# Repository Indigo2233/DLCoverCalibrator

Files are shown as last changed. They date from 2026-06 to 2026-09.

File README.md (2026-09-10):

# DarkLight Cover/Calibrator (DLC)

**DIY 电动天文望远镜盖 + 平场板** — 支持 ASCOM & INDI 全自动控制。

> 基于 [Nathan Woelfle 的原版设计](https://github.com/iwannabswiss/DarkLight_CoverCalibrator) 修改，遵循 CC BY-NC 4.0 协议。

---

## 三种构建方式

- **纯平场板** — 壁挂式校准面板（无需舵机）
- **纯电动盖** — 翻转盖，拍暗场和天光平场
- **Flip-Flat 组合** — 舵机 + 发光面板一体

---

## 🆕 改进亮点

| 改进 | 说明 |
|---|---|
| 🔧 **角度实时配置** | 不再需要刷固件！通过 ASCOM/INDI 软件直接调整开合角度 |
| 📡 **开源 ASCOM 驱动** | 从零编写，源码完全开放，Setup 界面配置角度 |
| 💾 **EEPROM 持久化** | 角度设置掉电保存，无需每次连接重新配置 |

---

## 📁 项目结构

```
├── dlc_firmware/          Arduino 固件
│   ├── dlc_firmware.ino   主程序
│   └── DLC_Library/       依赖库 (舵机/传感器/EEPROM)
├── esp8266_lenscap/       ESP8266 无线电动镜头盖固件
│   └── README.md           NodeMCU / Wemos 接线、刷写与 WiFi 使用说明
├── ascom/                 ASCOM 驱动 (Windows)
│   ├── DarkLightDriver/   🆕 自定义开源驱动 (C#)
│   └── *.msi/*.exe        原版闭源驱动
├── indi/                  INDI 驱动 (Linux/macOS)
│   └── indi-dlc-src/      C++ 源码
├── schematics/            硬件原理图 & PCB
└── docs/                  📚 文档
    ├── getting-started.md
    ├── firmware.md
    ├── protocol.md
    ├── ascom-driver.md
    ├── indi-driver.md
    └── changelog.md
```

---

## 🚀 快速开始

### ESP8266 无线镜头盖

使用 NodeMCU 或 Wemos D1 Mini 驱动舵机时，请参阅 [ESP8266 镜头盖固件说明](esp8266_lenscap/README.md)。

### 1. 刷固件
用 Arduino IDE 打开 `dlc_firmware/dlc_firmware.ino`，按需修改配置后上传。详见 [固件指南](docs/firmware.md)。

### 2. 安装驱动

**Windows（自定义开源驱动）:**
```batch
cd ascom\DarkLightDriver
dotnet build -c Release
Install.bat
```
详见 [ASCOM 驱动指南](docs/ascom-driver.md)。

**Linux:**
```bash
cd indi/indi-dlc-src
mkdir build && cd build
cmake .. && make -j$(nproc) && sudo make install
```
详见 [INDI 驱动指南](docs/indi-driver.md)。

### 3. 配置角度（🆕）
- **ASCOM**: Properties → Setup 界面直接修改
- **INDI**: Options 面板修改角度数值
- 自动保存到 EEPROM，无需重新刷固件

详细串口协议见 [通信协议文档](docs/protocol.md)。

---

## 📜 许可

© 2020–2025 Nathan Woelfle (10th Tee Astronomy).  
修改部分 © 2025.

[CC BY-NC 4.0](https://creativecommons.org/licenses/by-nc/4.0/) — 个人/学术用途自由使用，商用需授权。

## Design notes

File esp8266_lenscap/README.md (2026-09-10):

# ESP8266 电动镜头盖 — 精简版

## 当前网络功能

- 唯一 AP：`LensCap-<设备ID>`，默认密码 `telescope`
- 控制页面：`http://192.168.4.1/`，支持盖板控制和平场灯 1–255 亮度调节
- 配置页面：`http://192.168.4.1/config`，可配置 STA、开盖位置和关盖位置，参数保存到 EEPROM
- DLC TCP 服务：端口 `4030`，协议与 USB 串口相同，命令使用 `<`、`>` 封装
- AP 在 STA 模式下保持启用，便于连接失败时恢复配置

ASCOM 使用 USB 时选择 `Serial` 和 115200 baud；使用 WiFi 时选择 `TCP`，填写配置页显示的 STA IP 和端口 `4030`。

基于 ESP8266 + 舵机的无线电动天文望远镜盖。
**完全兼容 DLC ASCOM/INDI 驱动。**

## 特性

| 功能 | 说明 |
|---|---|
| 📱 **Web 控制** | 手机/电脑浏览器打开网页即可开关盖子 |
| 🔘 **物理按键** | 短按切换开关状态（可选，不接也行） |
| 🔌 **ASCOM/INDI** | ✅ 完整 DLC 串口协议，直接配合现有驱动使用 |
| 💾 **角度持久化** | EEPROM 保存开合角度，ASCOM Setup 界面修改自动保存 |
| 📡 **WiFi AP** | 自带热点，野外无路由器也能用 |
| ⚡ **平滑移动** | 线性插值缓动，可设移动时间 |

## ASCOM/INDI 兼容性

| 命令组 | 状态 | 说明 |
|---|:----:|---|
| 盖子 O/C/H/P | ✅ 完整支持 | 开关盖、停止、状态查询 |
| 角度 UO/UC/uO/i | ✅ 完整支持 | ASCOM Setup 里直接改角度，自动写入 EEPROM |
| 平场板 L/B/M/T/F | ✅ 兼容应答 | 本设备无平场板，返回 NotPresent/0 |
| 加热器 R/W/Y | ✅ 兼容应答 | 本设备无加热器，返回 NotPresent/0 |
| 系统 V/Z | ✅ 完整支持 | 版本查询、握手 |

> 在 NINA / SGPro / KStars 中直接选择 "DarkLight Cover Calibrator" 驱动即可使用。
> ASCOM 驱动轮询平场板和加热器状态时不会报错。

## 硬件接线

```
Wemos D1 Mini / NodeMCU      外部器件
────────────────────────     ──────────
D2 (GPIO4)  ──────────────   舵机 信号线 (橙/黄)
5V / VIN    ──────────────   舵机 电源 (红)  ← 必须独立供电
GND         ──────────────   舵机 GND  (棕)
GND         ──────────────   电源 GND
D1 (GPIO5)  ───[按键]─── GND
D3 (GPIO0)  ───[LED]──── GND  (可选，状态指示)
```

> ⚠️ **重要**: 舵机电源必须接 **5V pin** 或外部 5V 电源，**不要接 3.3V pin**！
> MG996R 等大扭矩舵机建议独立 5V/2A 供电。

### NodeMCU ESP-12F 接线（CH340 版本）

本固件已在 NodeMCU ESP-12F 开发板上验证。该板上标记为 `VU` 的针脚是 USB 5V 电源，外观上容易与 `VV` 混淆。

| 舵机线 | NodeMCU 针脚 | 说明 |
|---|---|---|
| 白 / 橙 / 黄 | `D2`（GPIO4） | 控制信号 |
| 红 | `VU` | USB 5V；适用于 SG90 等小型舵机 |
| 黑 / 棕 | `G` | 接地 |

`D2` 位于下排、靠右侧第三个 I/O 针脚。`3V` 针脚不用于舵机供电。

对于 MG90、MG996R 等电流较大的舵机，将红线连接到独立的稳定 5V 电源；外部电源 GND 与 NodeMCU 的 `G` 必须共地。建议在舵机电源线附近并联一个 **470–1000 µF、耐压至少 6.3V** 的电解电容，电容正极接 5V、负极接 GND；可另加 0.1 µF 陶瓷电容抑制高频干扰。

## 固件配置

打开 `esp8266_lenscap.ino`，修改顶部 `USER CONFIGURATION` 区域：

```cpp
// WiFi 热点名称和密码
const char* apSSID = "LensCap";
const char* apPassword = "telescope";  // 至少 8 位，空字符串 = 不加密

// 舵机角度 (0-180)
const uint16_t OPEN_ANGLE = 0;      // 开盖角度
const uint16_t CLOSE_ANGLE = 180;   // 关盖角度
const uint16_t MOVE_TIME_MS = 2000; // 开合时间 (毫秒)

// 舵机脉冲范围 (查舵机说明书)
const uint16_t SERVO_MIN_US = 500;
const uint16_t SERVO_MAX_US = 2500;
```

## 刷写步骤

1. **安装 ESP8266 开发板支持**  
   Arduino IDE → 文件 → 首选项 → 附加开发板管理器网址，添加：  
   `http://arduino.esp8266.com/stable/package_esp8266com_index.json`  
   然后：工具 → 开发板 → 开发板管理器 → 搜索 `ESP8266` → 安装

2. **选择开发板**  
   - Wemos D1 Mini：工具 → 开发板 → ESP8266 → **LOLIN(WEMOS) D1 R2 & mini**
   - NodeMCU ESP-12F：工具 → 开发板 → ESP8266 → **NodeMCU 1.0 (ESP-12E Module)**

3. **安装依赖库**  
   工具 → 管理库 → 搜索并安装：
   - `ESP8266WiFi` (自带)
   - `ESP8266WebServer` (自带)
   - `Servo` (自带，但 ESP8266 版在 ESP8266 包中)

4. **上传**  
   连接 USB，选择端口，点击上传。

## 使用

### 方式一：手机 Web 控制 (推荐)

1. 上电后 ESP8266 创建热点 `LensCap-<设备ID>`（密码 `telescope`）
2. 手机连接该 WiFi
3. 浏览器打开 **http://192.168.4.1**
4. 点击按钮开关盖子

设备 ID 取自 ESP8266 芯片 ID 的十六进制后六位。例如，芯片 ID 为 `513670` 时，热点名称为 `LensCap-513670`。

### 方式二：物理按键

按一下按键 → 切换开关状态（关→开，开→关）

### 方式三：串口命令 (ASCOM/INDI)

通过 USB 串口发送命令（115200 baud）：

| 命令 | 功能 |
|---|---|
| `<O>` | 开盖 |
| `<C>` | 关盖 |
| `<H>` | 立即停止 |
| `<P>` | 查询状态 (1=关,2=移动中,3=开,5=错误) |

此协议兼容 DLC 固件子集，可直接配合 ASCOM/INDI 驱动使用。

## 结构设计建议

### 3D 打印件

- [Thingiverse: Telescope Lens Cap Servo Mount](https://www.thingiverse.com/search?q=telescope+lens+cap+servo)
- 设计要点：舵机固定在镜筒侧面，连杆连接盖子

### 简易方案 (无需 3D 打印)

```
舵机 ──[连杆]── 盖子 (3D 打印件 / 亚克力切割 / 硬纸板+黑色植绒)
  │
  ├── 用抱箍/扎带固定在望远镜镜筒上
  └── 舵机转轴与盖子轴心对齐
```

## 可选增强

| 功能 | 实现方式 |
|---|---|
| 接入家庭 WiFi | 取消 `WIFI_STA_MODE` 注释，填写路由器 SSID/密码 |
| MQTT 远程控制 | 添加 `PubSubClient` 库，接入 Home Assistant |
| 平场板集成 | 加 LED 灯板 + MOSFET，用 GPIO 控制亮度 |
| 电池供电 | 2S 锂电池 (7.4V) + LM2596 降压模块 → 5V |
| 低功耗 | 加 `ESP.deepSleep()`，按键唤醒 |

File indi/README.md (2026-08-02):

# INDI Driver: DarkLight Cover Calibrator

This is the INDI driver source code for the **DarkLight Cover Calibrator (DLC)**. It enables control of the DLC hardware via the INDI protocol, providing compatibility with astronomy software on Linux systems.

---

## 🔖 Firmware Version

📄 See full [INDI Version History](https://github.com/10thTeeAstronomy/DarkLight_CoverCalibrator/wiki/INDI-Version-History)

---

## 📦 Features

- Cover control (Open/Close/Halt)  
- Calibrator control (On/Off/Brightness)  
- Dew heater  control  
- Support for ASCOM-style commands over INDI  
- Fully compatible with INDI clients like KStars and Ekos  

---

## 🛠️ Building and Installing

To compile and install the driver from source:

### 1. Clone the repository
```bash
git clone https://github.com/Indigo2233/DLCoverCalibrator.git
cd DLCoverCalibrator/indi/indi-dlc-src
```

### 2. Create a `build` directory
```bash
mkdir build
cd build
```

### 3. Run `cmake`
```bash
cmake -DCMAKE_INSTALL_PREFIX=/usr -DCMAKE_BUILD_TYPE=Release ..
```

### 4. Compile the driver
```bash
make
```

### 5. Install the driver
```bash
sudo make install
```

---

## 📚 Resources

- Main Project: [DarkLight Cover Calibrator GitHub](https://github.com/10thTeeAstronomy/DarkLight_CoverCalibrator)  
- Firmware: [dlc_firmware](https://github.com/10thTeeAstronomy/DarkLight_CoverCalibrator/tree/main/dlc_firmware)  
- Documentation: See the [GitHub Wiki](https://github.com/10thTeeAstronomy/DarkLight_CoverCalibrator/wiki)  

---

## 🤝 Contributing

We welcome contributions! Please see the `CONTRIBUTING.md` file in the root project for intallation and guidelines on submitting pull requests.

---

## 📜 License

© 2020–2025 10th Tee Astronomy. All rights reserved.

This project is licensed under the  
**Creative Commons Attribution-NonCommercial 4.0 International License**.

- You may share and adapt the materials for personal or academic use  
- Commercial use is prohibited without written permission  
- Modified versions must credit the original work  

See `LICENSE.md` for full terms.  

**Happy imaging!**  
— *The 10thTeeAstronomy Team*

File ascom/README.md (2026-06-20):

# ASCOM Driver and Application

This is the ASCOM-compatible driver and application for the **DarkLight Cover Calibrator (DLC)**. It provides full support for Windows-based astronomy applications that use the ASCOM platform.

> 🆕 **Custom Open-Source Driver**: See [DarkLightDriver/](DarkLightDriver/) for a from-scratch, open-source ASCOM driver with **configurable servo open/close angles** — no more firmware flashing to adjust angles!

---

## 🔖 Firmware Version

📄 See full [ASCOM Version History](https://github.com/10thTeeAstronomy/DarkLight_CoverCalibrator/wiki/ASCOM-Version-History)

---

## 📦 Features

- Full support and compliance using the ASCOM **ICoverCalibratorV2** interface  
- Cover control (Open/Close/Halt)  
- Light control with adjustable brightness  
- Dew heater support (manual, automatic, and "on close" modes)  
- Standalone Windows application available 

---

## 🛠️ Installing the Driver

To install the driver:

1. **Clone** or **Download** the latest [Release](https://github.com/10thTeeAstronomy/DarkLight_CoverCalibrator/releases).
2. **Open** the ```ascom``` folder.
2. **Run the installer**, ```DarkLight_Driver_Setup```, and follow the on-screen instructions.
3. Once installed, the driver will appear in the ASCOM Chooser as:
   ```
   DarkLight Cover Calibrator
   ```

> ℹ️ ASCOM Platform 7 or newer is required for DLC version 1.2 and newer. You can download it from [ascom-standards.org](https://ascom-standards.org/).

---

## ⚙️ Configuring the Driver

Refer to the [ASCOM Integration Guide](https://github.com/10thTeeAstronomy/DarkLight_CoverCalibrator/wiki/ASCOM-Integration).

---

## 🪟 Installing the Application

To install the application:

1. **Clone** or **Download** the latest [Release](https://github.com/10thTeeAstronomy/DarkLight_CoverCalibrator/releases).
2. **Open** the ```ascom``` folder.
2. **Run the installer**, ```DarkLight_App_Setup```, and follow the on-screen instructions.
3. Once installed, run the program and select the ```DarkLight Cover Calibrator```.

---

## ⚙️ Configuring the Application

Refer to the [Windows Application Guide](https://github.com/10thTeeAstronomy/DarkLight_CoverCalibrator/wiki/Windows-Application).

---

## 📚 Resources

- Main Project: [DarkLight Cover Calibrator GitHub](https://github.com/10thTeeAstronomy/DarkLight_CoverCalibrator)  
- Firmware: [dlc_firmware](https://github.com/10thTeeAstronomy/DarkLight_CoverCalibrator/tree/main/dlc_firmware)  
- Documentation: See the [GitHub Wiki](https://github.com/10thTeeAstronomy/DarkLight_CoverCalibrator/wiki)  
- ASCOM CoverCalibrator Info: [ASCOM Device Interface](https://ascom-standards.org/help/developer/html/T_ASCOM_DeviceInterface_ICoverCalibratorV2.htm)

---

## 🤝 Contributing

We welcome contributions! Please see the `CONTRIBUTING.md` file in the root project for guidelines on submitting pull requests.

---

## 📜 License

© 2020–2025 10th Tee Astronomy. All rights reserved.

This project is licensed under the  
**Creative Commons Attribution-NonCommercial 4.0 International License**.

- You may share and adapt the materials for personal or academic use  
- Commercial use is prohibited without written permission  
- Modified versions must credit the original work  

See `LICENSE.md` for full terms.  

**Happy imaging!**  
— *The 10thTeeAstronomy Team*

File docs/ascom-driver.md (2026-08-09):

# 自定义 ASCOM 驱动

源码位于 `ascom/DarkLightDriver/`，是从头编写的开源 ASCOM CoverCalibrator V2 驱动。

## 与原版驱动的对比

| 功能 | 原版驱动 (闭源) | 本驱动 (开源) |
|---|:---:|:---:|
| Cover 开/关/停 | ✓ | ✓ |
| 平场板亮度控制 | ✓ | ✓ |
| 除露加热控制 | ✓ | ✓ |
| 宽带/窄带亮度预设 | ✓ | ✓ |
| **主舵机开合角度配置** | ✗ | **✓** |
| **源码可修改** | ✗ | **✓** |

## 项目结构

```
ascom/DarkLightDriver/
├── DarkLightDriver.csproj    # .NET Framework 4.8 项目
├── Driver.cs                 # ICoverCalibratorV2 主驱动
├── DeviceSerial.cs           # 串口通信封装
├── SetupDialogForm.cs        # 配置对话框
├── Properties/AssemblyInfo.cs
├── Install.bat               # 安装脚本
├── Uninstall.bat             # 卸载脚本
└── README.md
```

## 编译要求

- Windows 10/11
- [ASCOM Platform 7+](https://ascom-standards.org/)
- .NET Framework 4.8 SDK
- Visual Studio 2022 或 `dotnet` CLI

## 编译

```batch
cd ascom\DarkLightDriver
dotnet build -c Release
```

## 安装

1. **以管理员身份**打开命令行
2. 运行安装脚本：
   ```batch
   Install.bat
   ```
3. 驱动会注册到 COM，出现在 ASCOM Chooser 中

## 卸载

```batch
Uninstall.bat
```

## Setup 界面

在 ASCOM Chooser 中选中驱动，点击 **Properties** 打开配置：

### Serial Connection
- **COM Port** — 下拉选择 + ↻ 刷新按钮
- **Baud Rate** — 9600 / 19200 / 38400 / 57600 / **115200** / 230400

### Servo Angles
- **Open Angle** — 开盖时舵机目标角度 (0–270°)
- **Close Angle** — 关盖时舵机目标角度 (0–270°)

### Polling
- **Poll Interval** — 状态轮询间隔 (500–10000 ms)

## 工作流程

1. 用户在 **Setup 界面**配置角度 → 保存到 Windows 注册表
2. 驱动 **连接设备**时 → 自动将角度推送到固件 EEPROM
3. 每次 **Open/Close** 命令前 → 重新同步确保角度一致
4. 驱动持续**轮询**设备状态，更新 `CoverState` / `CalibratorState`

## 故障排查

| 问题 | 解决方案 |
|---|---|
| 驱动不在 Chooser 中 | 以管理员运行 `Install.bat` |
| 连接失败 | 检查 COM 端口和 115200 波特率 |
| 握手失败 | 固件需编译 `ENABLE_SERIAL_CONTROL` |
| 运行中连续无响应 | 驱动会自动停止轮询、执行 DTR 复位并重建串口 |
| 自动恢复失败 | 在 ASCOM Actions 中执行 `ResetDevice`；仍失败时重新插拔 USB，或在设备管理器中禁用后重新启用 CH340 |
| 角度设置无效 | 更新固件支持 `UO`/`UC` 等命令 |

## 技术细节

- **接口**: `ICoverCalibratorV2` (ASCOM Platform 7)
- **通信**: Serial port, `<command>` 帧协议
- **持久化**: ASCOM Profile (Windows Registry)
- **轮询**: `System.Timers.Timer` 定时刷新状态
- **线程安全**: 串口操作和连接切换使用互斥保护，轮询回调禁止重入
- **恢复策略**: 握手失败时执行一次 DTR 复位和串口重建；运行期连续两次轮询失败后自动恢复

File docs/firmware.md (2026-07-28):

# 固件配置指南

固件文件：`dlc_firmware/dlc_firmware.ino`

## 当前 DLC 板烧录信息

当前通过 CH340 串口连接的 DLC 板实际使用 **ATmega328PB**。应通过
[MiniCore](https://github.com/MCUdude/MiniCore) 编译和上传；Arduino Nano 的
`arduino:avr:nano` 配置无法与该板的 bootloader 正常握手。

- 开发板索引：`https://mcudude.github.io/MiniCore/package_MCUdude_MiniCore_index.json`
- MiniCore 版本：`3.1.2`
- 开发板 FQBN：`MiniCore:avr:328:variant=modelPB`
- 默认配置：外部 16 MHz、UART0 bootloader、保留 EEPROM
- 当前 Windows 串口：`COM3`（端口号可能随 USB 接口变化）
- 固件串口速率：`115200`

安装 MiniCore：

```powershell
arduino-cli core update-index --additional-urls "https://mcudude.github.io/MiniCore/package_MCUdude_MiniCore_index.json"
arduino-cli core install MiniCore:avr --additional-urls "https://mcudude.github.io/MiniCore/package_MCUdude_MiniCore_index.json"
```

编译并烧录：

```powershell
arduino-cli compile --fqbn MiniCore:avr:328:variant=modelPB --libraries dlc_firmware/DLC_Library dlc_firmware
arduino-cli upload -p COM3 --fqbn MiniCore:avr:328:variant=modelPB dlc_firmware
```

烧录完成后，可通过串口发送 `<V>` 验证固件响应。2026-07-27 的烧录结果为
`<v1.2.0>`。

## 配置选项一览

固件顶部 **User-Adjustable Options (UA)** 区域可以调整所有参数：

### 功能开关

```cpp
#define COVER_INSTALLED        // 启用盖子（舵机）
#define LIGHT_INSTALLED        // 启用平场板
#define HEATER_INSTALLED       // 启用除露加热
#define ENABLE_SERIAL_CONTROL  // 启用串口控制（ASCOM/INDI）
#define ENABLE_MANUAL_CONTROL  // 启用手动物理按钮
#define ENABLE_SAVING_TO_MEMORY // 启用 EEPROM 掉电保存
```

> 不需要的功能直接注释掉即可，固件会自动调整状态上报。

### 串口速率

```cpp
const uint32_t serialSpeed = 115200;
```

可选值：`9600`、`19200`、`38400`、`57600`、`115200`（默认）、`230400`

### 舵机参数

```cpp
// 脉冲宽度 — 查阅舵机说明书设置
const uint16_t primaryServoMinPulseWidth = 500;   // μs
const uint16_t primaryServoMaxPulseWidth = 2500;  // μs

// 开合角度 — 可通过 ASCOM/INDI 实时修改，自动保存到 EEPROM
uint16_t primaryServoOpenCoverAngle = 0;    // 开盖角度 (0–270)
uint16_t primaryServoCloseCoverAngle = 180; // 关盖角度 (0–270)
```

### 盖子移动

```cpp
const uint32_t timeToMoveCover = 5000;  // 开合全程时间 (ms)
```

### 缓动曲线

7 种可选，只取消注释一个：
| 宏 | 效果 |
|----|---|
| `USE_LINEAR` | 匀速（默认） |
| `USE_QUAD` | 二次缓动 |
| `USE_CUBIC` | 三次缓动 |
| `USE_QUART` | 四次缓动 |
| `USE_QUINT` | 五次缓动 |
| `USE_SINE` | 正弦缓动 |
| `USE_EXPO` | 指数缓动 |
| `USE_CIRCULAR` | 圆形缓动 |

### 平场板

```cpp
uint8_t maxBrightness = 255;  // 亮度等级数（越大越细腻）
bool autoON = false;          // 仅手动模式：关盖时自动开灯
```

### 除露加热

```cpp
const uint32_t heaterShutoff = 3600000;  // 手动加热最长持续时间 (ms)
const float deltaPoint = 5.0;             // 目标温度高于环境温度 (°C)
```

### 副舵机

如果需要双舵机驱动：
```cpp
#define SECONDARY_SERVO_INSTALLED  // 取消注释
```

## 角度实时调整（新功能）

不再需要修改固件重新烧录！通过 ASCOM Setup 界面或 INDI Options 面板直接修改角度：

- **主舵机开盖角度** (`UO<N>`) — 0–270°
- **主舵机关盖角度** (`UC<N>`) — 0–270°
- **副舵机开盖角度** (`VO<N>`) — 0–270°（需启用副舵机）
- **副舵机关盖角度** (`VC<N>`) — 0–270°（需启用副舵机）

修改后自动保存到 EEPROM，断电不丢失。

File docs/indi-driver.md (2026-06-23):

# INDI 驱动

源码位于 `indi/indi-dlc-src/`，支持 Linux/macOS 上的 INDI 协议。

## 编译与安装

```bash
cd indi/indi-dlc-src
mkdir build && cd build
cmake -DCMAKE_INSTALL_PREFIX=/usr -DCMAKE_BUILD_TYPE=Release ..
make -j$(nproc)
sudo make install
```

## 依赖

- libindi (INDI 开发库)
- CMake 3.0+

Ubuntu/Debian 安装依赖：
```bash
sudo apt install libindi-dev cmake build-essential
```

## 属性面板

连接设备后在 INDI 控制面板可看到：

### Main Control 选项卡

| 属性 | 类型 | 说明 |
|---|---|---|
| Cover State | 只读文本 | 盖子状态 (Open/Closed/Moving/Error) |
| Open / Close / Halt | 开关按钮 | 控制盖子动作 |
| Light State | 只读文本 | 平场板状态 |
| On / Off | 开关按钮 | 开关平场板 |
| Max Brightness | 只读数字 | 最大亮度值 |
| Current Brightness | 只读数字 | 当前亮度 |
| Goto Brightness | 输入数字 | 跳转到指定亮度 |
| - / + | 按钮 | 步进调整亮度 |
| Broadband / Narrowband | 按钮 | 跳转到预设值 |
| Save as Broadband / Narrowband | 按钮 | 保存当前值为预设 |
| Heater State | 只读文本 | 加热器状态 |
| On / Off / Auto / Heat on Close | 开关按钮 | 加热控制 |

### Options 选项卡

| 属性 | 说明 |
|---|---|
| Stabilize Time | 平场板稳定时间 (ms) |
| Auto ON at CLOSE | 关盖时自动开灯 |
| Disable Light while OPEN | 开盖时禁用灯光 |
| Auto Heat (always ON) | 常开自动除露 |
| Heat ON at CLOSE | 关盖时开启加热 |
| 🆕 **Open Angle (0–270)** | **主舵机开盖角度** |
| 🆕 **Close Angle (0–270)** | **主舵机关盖角度** |
| 🆕 **2nd Open Angle (0–270)** | **副舵机开盖角度** |
| 🆕 **2nd Close Angle (0–270)** | **副舵机关盖角度** |

## KStars / Ekos 集成

1. 启动 INDI 服务
2. 在 Ekos 中配置设备
3. 选择 "DarkLight Cover Calibrator"
4. 平场拍摄时自动调用 `CalibratorOn()`
5. 暗场拍摄时自动调用 `CloseCover()` + `CalibratorOff()`

## 架构

```
Ekos/KStars
    │ INDI Protocol (TCP)
    ▼
indi-dlc driver (C++)
    │ Serial Protocol (<cmd>)
    ▼
Arduino DLC Firmware
    │ PWM / GPIO
    ▼
Servo / LED / Heater
```

驱动类 `DarkLight_CoverCalibrator` 继承 `INDI::DefaultDevice`，通过 `Connection::Serial` 管理串口连接。

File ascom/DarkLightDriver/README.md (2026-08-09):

# DarkLight Cover Calibrator — Custom ASCOM Driver

## 1.2.0 连接方式

- `Serial`：Arduino Nano 或 ESP8266 USB 串口，默认 115200 baud
- `TCP`：ESP8266 的 STA/AP 地址，默认端口 `4030`

两种传输使用相同的 DLC `<命令>` 协议。TCP 模式下建议在路由器为设备保留固定 DHCP 地址。

这是一个从头编写的 ASCOM CoverCalibrator V2 驱动，支持直接配置舵机开合角度。

## 与原版驱动的区别

| 功能 | 原版驱动 | 本驱动 |
|---|---|---|
| Cover 开/关/停 | ✓ | ✓ |
| 平场板亮度控制 | ✓ | ✓ |
| 除露加热控制 | ✓ | ✓ |
| **主舵机开合角度配置** | ✗ (需刷固件) | **✓ (Setup 界面)** |
| 源码可修改 | ✗ (闭源) | **✓ (开源)** |

## 前提条件

- Windows 10/11
- [ASCOM Platform 7](https://ascom-standards.org/) 或更新版本
- .NET Framework 4.8
- DLC 固件已刷入并支持角度命令（`UO`、`UC`、`uO`、`i`）

## 编译

```bash
# 在 Windows 上使用 Visual Studio 或命令行：
cd ascom/DarkLightDriver
dotnet build -c Release
```

或者用 Visual Studio 打开 `DarkLightDriver.csproj`，直接 Build。

## 安装

1. 确保已安装 ASCOM Platform 7+
2. 编译项目得到 `DarkLight.CoverCalibrator.dll`
3. **以管理员身份**运行 `Install.bat`

## 配置（Setup 界面）

在 ASCOM Chooser 中选中 "DarkLight Cover Calibrator"，点击 **Properties**。

界面采用 **Gemini FlatPanel 风格**，支持连接设备后的**实时角度微调**：

### Serial Connection（顶部工具栏）
- **COM Port** — 下拉选择 + ↻ 刷新
- **Baud Rate** — 9600~230400
- 连接状态指示灯 + 固件版本显示

### 舵机角度

每个面板包含两组控制：

**关闭方向** (橙色)
- 当前角度值（大字体）+ **±1° / ±10° / ±45°** 实时微调
- 「设为关闭位置」一键保存当前位置

**打开方向** (绿色)
- 当前角度值（大字体）+ **±1° / ±10° / ±45°** 实时微调
- 「设为打开位置」一键保存当前位置

### 底部按钮
- **重设** — 恢复默认角度（开=0° 关=180°）
- **Done** — 保存并关闭

### 实时微调工作流
1. 连接设备后打开 Setup 界面
2. 点击 ±1°/±10°/±45° 按钮实时移动舵机到位
3. 点击「设为关闭/打开位置」保存
4. 角度自动写入固件 EEPROM，断电不丢失

## 卸载

**以管理员身份**运行 `Uninstall.bat`。

## 串口协议

本驱动与 DLC 固件通过以下串口命令通信（`<` 和 `>` 包裹）：

| 命令 | 功能 |
|---|---|
| `O` / `C` / `H` | 开盖 / 关盖 / 停止 |
| `P` | 查询盖子状态 |
| `L` / `B` / `M` | 查询平场板状态 / 亮度 / 最大亮度 |
| `T<值>` / `F` | 开平场板 / 关平场板 |
| `UO<角度>` / `UC<角度>` | 设置主舵机开/关角度（写入 EEPROM） |
| `uO` / `i` | 查询主舵机开/关角度 |
| `J<角度>` / `j` | 🆕 Jog 主舵机直驱 / 查询当前位置 |
| `Z` | 握手（返回 `?`） |
| `V` | 查询固件版本 |

## 工作原理

1. **Setup 界面**配置角度 → 保存到 Windows 注册表 (ASCOM Profile)
2. 驱动**连接设备**时 → 自动将配置的角度推送到固件 EEPROM
3. 每次 **Open/Close** 命令前 → 重新同步角度确保一致
4. 固件 EEPROM 保存角度 → 即使不连接 ASCOM 也能记住上次的角度

## 故障排查

| 问题 | 解决方案 |
|---|---|
| 设备连接失败 | 检查 COM 端口号和波特率 (115200) |
| 握手失败 (返回不是 `?`) | 确认固件已编译 `ENABLE_SERIAL_CONTROL` |
| 运行中连续无响应 | 驱动会在两次失败的轮询周期后自动释放并重建连接 |
| 自动恢复失败 | 在 NINA/ASCOM Actions 中执行 `ResetDevice`；仍失败时重新插拔 USB，或在 Windows 设备管理器中禁用后重新启用 CH340 |
| 角度设置无效 | 确认已更新固件支持 `UO`/`UC` 等命令 |
| 驱动不出现在 ASCOM Chooser | 以管理员运行 `Install.bat` |

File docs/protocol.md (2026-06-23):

# 串口通信协议

DLC 固件与上位机（ASCOM/INDI 驱动）通过串口通信。

## 帧格式

所有命令和响应由 `<` 和 `>` 包裹：

```
发送: <命令>
响应: <响应内容>
```

## 完整命令列表

### 盖子控制

| 命令 | 参数 | 响应 | 说明 |
|---|---|---|---|
| `O` | 无 | 回显 `O` | 开盖 |
| `C` | 无 | 回显 `C` | 关盖 |
| `H` | 无 | 回显 `H` | 停止移动 |
| `P` | 无 | `0`–`5` | 查询盖子状态 |

**盖子状态码：**
| 值 | 含义 |
|----|---|
| 0 | NotPresent（未安装） |
| 1 | Closed（已关闭） |
| 2 | Moving（移动中） |
| 3 | Open（已打开） |
| 4 | Unknown（未知） |
| 5 | Error（错误） |

### 平场板控制

| 命令 | 参数 | 响应 | 说明 |
|---|---|---|---|
| `L` | 无 | `0`–`5` | 查询平场板状态 |
| `B` | 无 | 数值 | 查询当前亮度 |
| `M` | 无 | 数值 | 查询最大亮度 |
| `T<N>` | 亮度值 | 回显 `T<N>` | 开灯并设亮度 |
| `F` | 无 | 回显 `F` | 关灯 |
| `A` | 无 | 回显 `A` | 设置 autoON=true |
| `a` | 无 | 回显 `a` | 设置 autoON=false |
| `S<N>` | 毫秒 | 回显 `S<N>` | 设置稳定时间 |

**平场板状态码：**
| 值 | 含义 |
|----|---|
| 0 | NotPresent |
| 1 | Off |
| 2 | NotReady |
| 3 | Ready |
| 4 | Unknown |
| 5 | Error |

### 宽带/窄带预设

| 命令 | 参数 | 响应 | 说明 |
|---|---|---|---|
| `DB` | 无 | 回显 `DB` | 保存当前亮度为宽带值 |
| `DN` | 无 | 回显 `DN` | 保存当前亮度为窄带值 |
| `GB` | 无 | 亮度值 | 跳转到宽带值 |
| `GN` | 无 | 亮度值 | 跳转到窄带值 |

### 除露加热控制

| 命令 | 参数 | 响应 | 说明 |
|---|---|---|---|
| `R` | 无 | `0`–`6` | 查询加热器状态 |
| `W` | 无 | 回显 `W` | 手动开启（带限时） |
| `w` | 无 | 回显 `w` | 关闭所有加热 |
| `Q` | 无 | 回显 `Q` | 设置 autoHeat=true |
| `q` | 无 | 回显 `q` | 设置 autoHeat=false |
| `E` | 无 | 回显 `E` | 设置 heatOnClose=true |
| `e` | 无 | 回显 `e` | 设置 heatOnClose=false |
| `Y` | 无 | 传感器数据 | 查询温湿度详情 |

**加热器状态码：**
| 值 | 含义 |
|----|---|
| 0 | NotPresent |
| 1 | Off |
| 2 | Auto |
| 3 | On |
| 4 | Unknown |
| 5 | Error |
| 6 | Set (HeatOnClose) |

### 🆕 舵机实时控制

| 命令 | 参数 | 响应 | 说明 |
|---|---|---|---|
| `UO<N>` | 角度 (0–270) | 回显 | 设置主舵机开盖角度（写入 EEPROM） |
| `UC<N>` | 角度 (0–270) | 回显 | 设置主舵机关盖角度（写入 EEPROM） |
| `VO<N>` | 角度 (0–270) | 回显 | 设置副舵机开盖角度 |
| `VC<N>` | 角度 (0–270) | 回显 | 设置副舵机关盖角度 |
| `uO` | 无 | 角度值 | 查询主舵机开盖角度 |
| `i` | 无 | 角度值 | 查询主舵机关盖角度 |
| `vO` | 无 | 角度值 | 查询副舵机开盖角度 |
| `vC` | 无 | 角度值 | 查询副舵机关盖角度 |
| `J<N>` | 角度 (0–270) | 回显 | 🆕 **Jog 主舵机**至指定角度（直驱，不改变保存值） |
| `j` | 无 | 角度值 | 🆕 查询主舵机当前物理位置 |
| `K<N>` | 角度 (0–270) | 回显 | 🆕 **Jog 副舵机**至指定角度 |
| `k` | 无 | 角度值 | 🆕 查询副舵机当前物理位置 |

> ⚠️ `VO`/`VC`/`vO`/`vC` 仅在固件编译了 `SECONDARY_SERVO_INSTALLED` 时有效，否则返回 `?`。

### 系统命令

| 命令 | 参数 | 响应 | 说明 |
|---|---|---|---|
| `V` | 无 | 版本号 | 查询固件版本 |
| `Z` | 无 | `?` | 握手测试 |

## 通信流程示例

```
PC → 设备: <P>
设备 → PC: <1>           (盖子状态 = Closed)

PC → 设备: <O>           (开盖)
设备 → PC: <O>           (确认)

PC → 设备: <P>
设备 → PC: <2>           (状态 = Moving)

... 等待 ...

PC → 设备: <P>
设备 → PC: <3>           (状态 = Open)

PC → 设备: <UO45>        (设开盖角度为 45°)
设备 → PC: <UO45>        (确认，已写入 EEPROM)
```

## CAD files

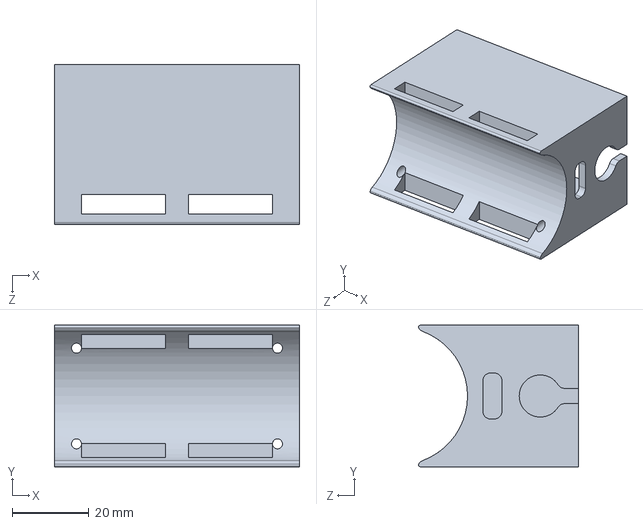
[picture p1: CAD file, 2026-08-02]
models/电动平场板/电平场壳子.STEP
64.0 x 37.0 x 41.8 mm

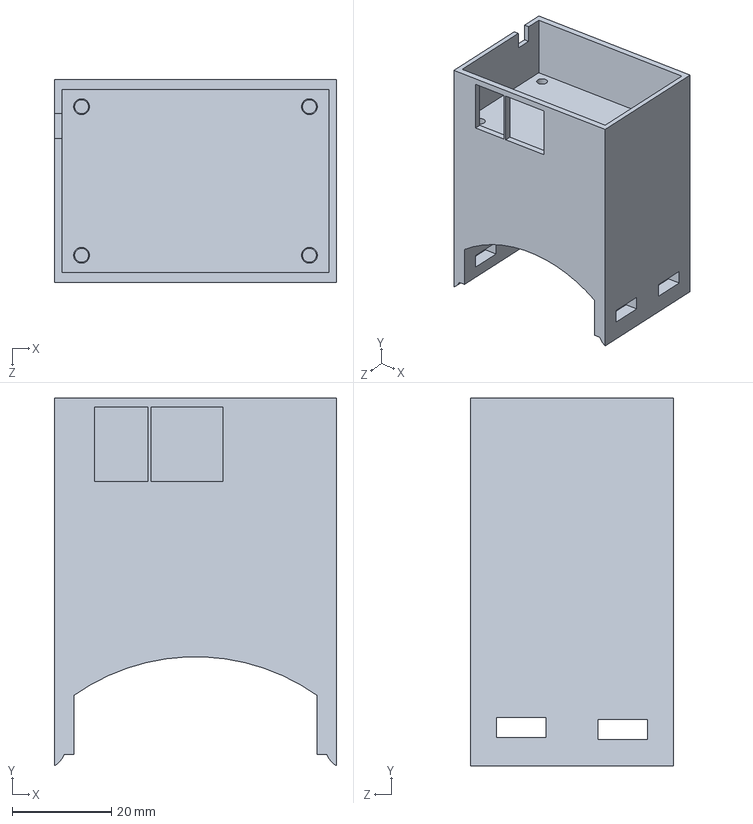
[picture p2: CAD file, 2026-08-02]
models/电动平场板/主控盒子-2.STEP
57.0 x 74.3 x 41.0 mm

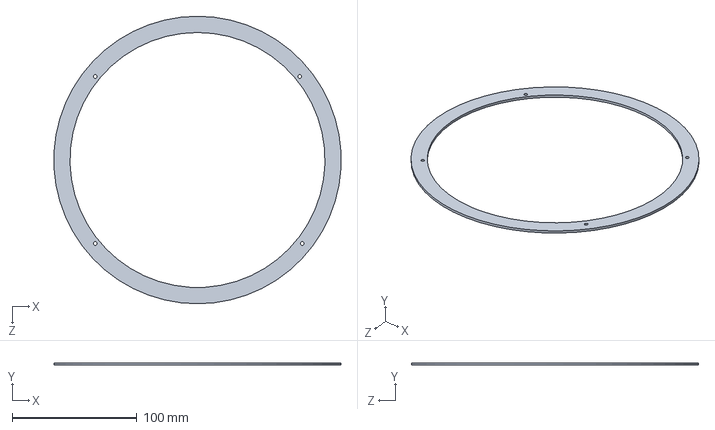
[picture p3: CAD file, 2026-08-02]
models/电动平场板/小黑平场板压圈 新.SLDPRT
229.6 x 2.00 x 230.0 mm

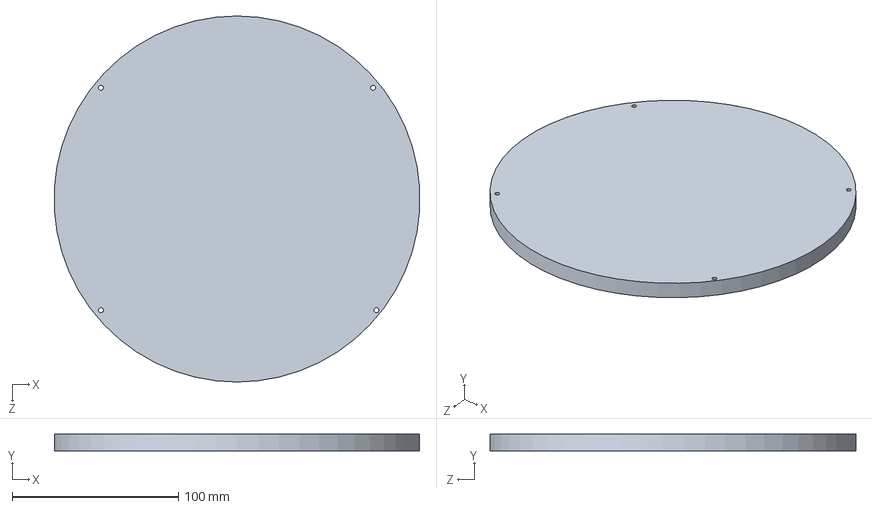
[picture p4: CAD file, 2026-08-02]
models/电动平场板/小黑平场板均光板.SLDPRT
219.6 x 10.0 x 220.0 mm

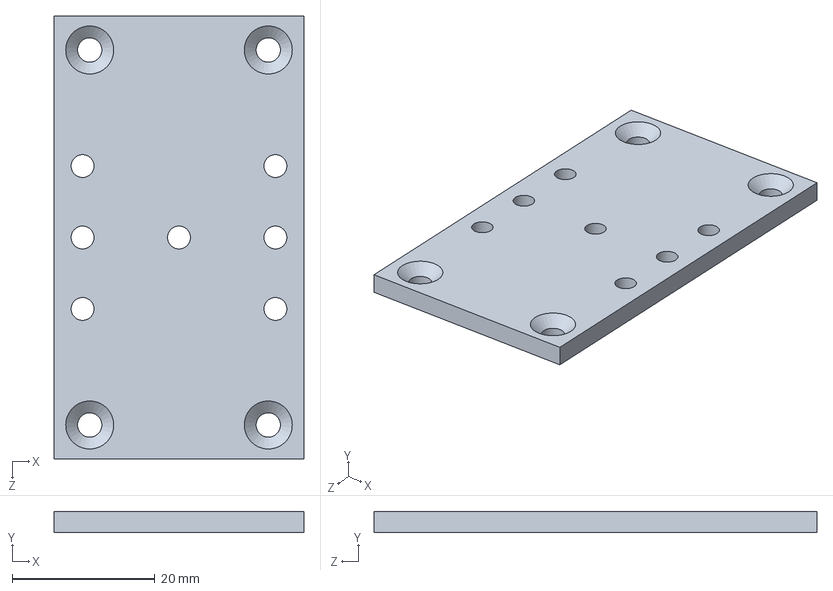
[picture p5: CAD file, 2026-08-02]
models/电动平场板/主控盒子-1.STEP
35.0 x 3.00 x 62.0 mm

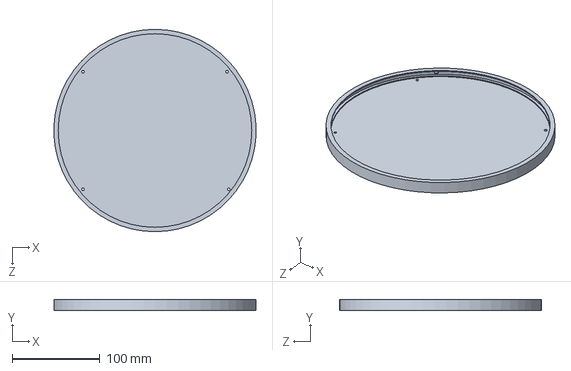
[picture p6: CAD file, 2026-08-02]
models/电动平场板/小黑平场板主体.SLDPRT
229.6 x 12.0 x 230.0 mm

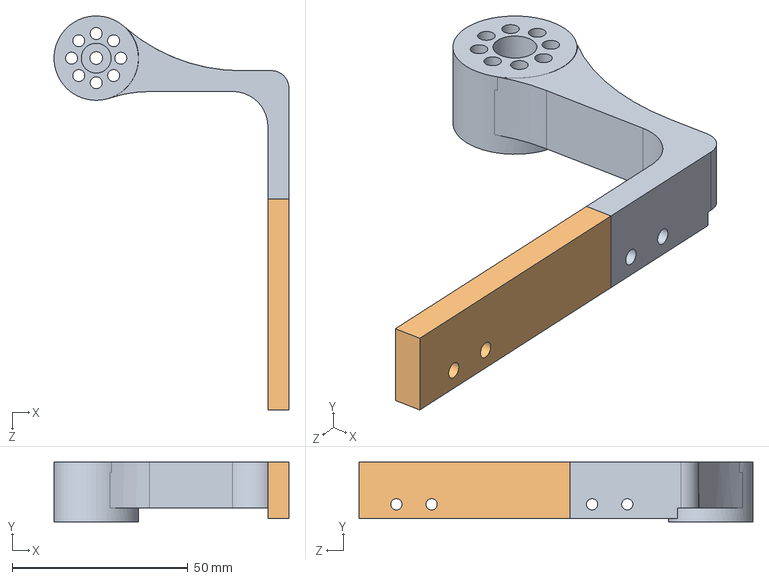
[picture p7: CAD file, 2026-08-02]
models/电动平场板/主动臂-反向.STEP
66.8 x 17.0 x 112.0 mm

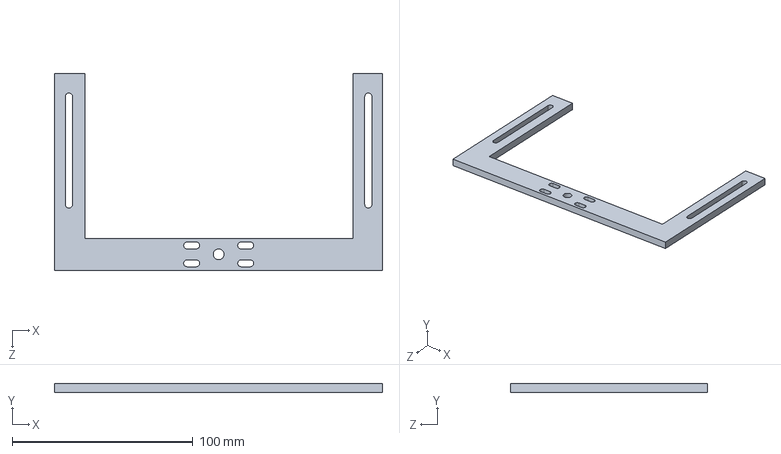
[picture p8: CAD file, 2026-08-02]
models/电动平场板/小黑连接板.SLDPRT
181.5 x 5.00 x 108.9 mm

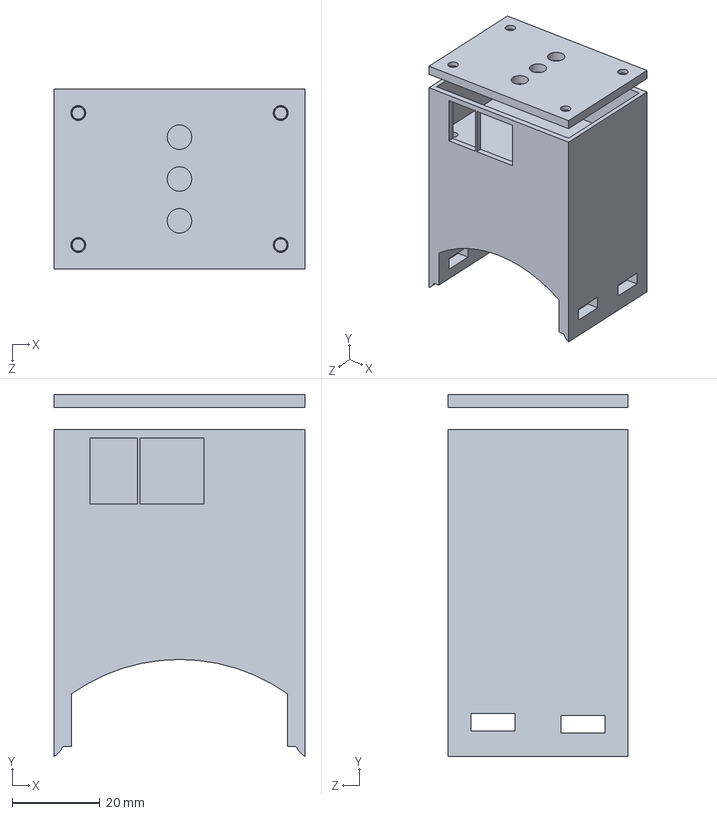
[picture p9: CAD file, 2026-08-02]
models/电动平场板/主控盒子.SLDPRT
57.0 x 82.3 x 41.0 mm

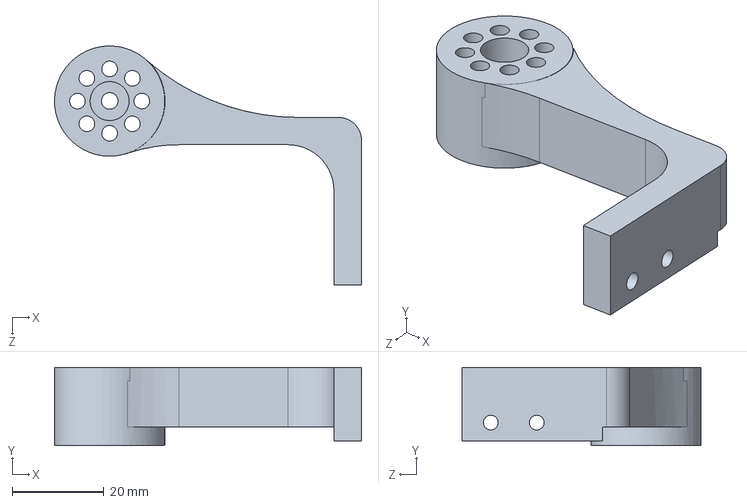
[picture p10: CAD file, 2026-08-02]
models/电动平场板/从动-正.STEP
66.8 x 17.0 x 52.0 mm

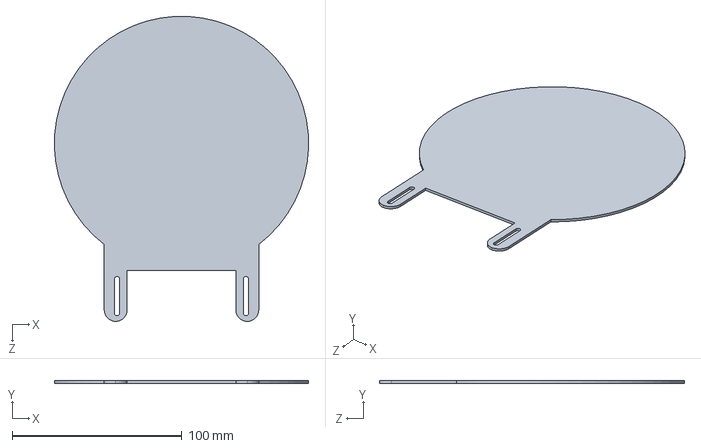
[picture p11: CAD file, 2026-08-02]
models/电动平场板/板子.STEP
149.9 x 1.50 x 179.9 mm

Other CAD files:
models/电动平场板/主动-反.STEP
models/电动平场板/主动臂-反向.SLDPRT
models/电动平场板/主控盒子-1.SLDPRT
models/电动平场板/电平场壳子.SLDPRT

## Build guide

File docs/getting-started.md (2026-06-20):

# DarkLight Cover Calibrator (DLC) — 快速入门

## 这是什么？

**DarkLight Cover Calibrator (DLC)** 是一个 DIY 电动天文望远镜盖 + 平场板的项目。你可以把它做成：

- **纯平场板** — 固定在墙上/望远镜前，用于拍摄平场（flat frame）
- **纯电动盖** — 舵机驱动的翻转盖，保护镜头+拍暗场（dark frame）
- **Flip-Flat 组合** — 盖子内侧集成发光面板，一机两用

## 硬件需求

| 组件 | 用途 |
|---|---|
| Arduino Nano/Uno | 主控 |
| 舵机 (SG90/MG996R 等) | 驱动盖子开合 |
| LED 平板 + 匀光片 | 平场光源 |
| DHT22 或 BME280 | 温湿度传感器（除露加热用） |
| DS18B20 ×2 | 温度传感器（加热器用） |
| MOSFET 模块 | 加热器功率控制 |
| 12V DC 电源 | 供电 |

完整 BOM 和接线图见 `schematics/` 目录。

## 快速开始

### 1. 刷固件

1. 用 Arduino IDE 打开 `dlc_firmware/dlc_firmware.ino`
2. 根据你的硬件配置修改 **User-Adjustable Options**：
   - 注释/取消注释 `COVER_INSTALLED`、`LIGHT_INSTALLED`、`HEATER_INSTALLED`
   - 设置舵机脉冲宽度范围（`primaryServoMinPulseWidth` / `primaryServoMaxPulseWidth`）
   - 选择缓动曲线（默认 `USE_LINEAR`）
3. 编译上传到 Arduino

> 💡 舵机开合角度**不再需要**在固件中硬编码！可以通过 ASCOM/INDI 软件实时调整，自动保存到 EEPROM。

### 2. 安装驱动

**Windows (ASCOM):**
```batch
# 先安装 ASCOM Platform 7+
# 编译自定义驱动
cd ascom\DarkLightDriver
dotnet build -c Release
# 以管理员运行
Install.bat
```

**Linux (INDI):**
```bash
cd indi/indi-dlc-src
mkdir build && cd build
cmake -DCMAKE_INSTALL_PREFIX=/usr -DCMAKE_BUILD_TYPE=Release ..
make -j$(nproc)
sudo make install
```

### 3. 连接使用

1. USB 连接 Arduino
2. 打开 ASCOM 客户端（NINA、SGPro 等）或 INDI 客户端（KStars/Ekos）
3. 选择 "DarkLight Cover Calibrator" 驱动
4. 在 Setup/Options 中配置串口和角度参数
5. 连接即可控制！

## 下一步

- [固件配置详解](firmware.md)
- [ASCOM 驱动使用](ascom-driver.md)
- [INDI 驱动使用](indi-driver.md)
- [串口通信协议](protocol.md)

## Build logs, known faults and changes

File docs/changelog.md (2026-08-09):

# 改动记录

> 本仓库基于 [DarkLight_CoverCalibrator](https://github.com/iwannabswiss/DarkLight_CoverCalibrator) (by Nathan Woelfle)  
> 遵循 CC BY-NC 4.0 协议进行修改。

## 2026-08 — ASCOM 驱动 1.2.0 串口恢复

### 问题

CH340 串口在远程运行中偶发打开成功但设备无响应。原有定时轮询允许回调重入，单次命令超时期间可能持续积压后续轮询；断开操作也会等待这些回调释放串口。

### 改动

- 握手采用有界恢复：首次无响应后执行 DTR 复位，释放旧 `SerialPort` 实例并重建串口
- 禁止状态轮询回调重入，并在首个无响应命令后结束本轮轮询
- 连续两轮无响应后自动停止轮询、恢复连接并重新读取设备状态
- 新增 ASCOM `ResetDevice` Action，用于手动执行同一恢复流程
- 连接失败重试次数固定为两轮，避免长时间无上限阻塞
- 从 ASCOM 驱动和 Setup 界面移除硬件未配备的副舵机设置及相关命令
- 增加串口恢复、轮询互斥和自动恢复回归测试

## 2025-06 — 舵机角度实时配置

### 问题
原版设计中，舵机开合角度（`primaryServoOpenCoverAngle`、`primaryServoCloseCoverAngle`）是固件编译时常量。每次调整角度都需要修改 `.ino` 文件重新编译烧录，非常不便。

### 改动

#### 固件 (`dlc_firmware/dlc_firmware.ino`)
- 角度变量从 `const` 改为可修改的 `uint8_t`
- 新增 4 个 EEPROM 存储位（掉电不丢失）
- 新增 8 条串口命令：`UO`/`UC`/`VO`/`VC`（设置角度）、`uO`/`i`/`vO`/`vC`（查询角度）
- 启动时自动从 EEPROM 加载角度，首次使用默认值

#### INDI 驱动 (`indi/indi-dlc-src/`)
- 新增 `PrimaryOpenAngleNP`、`PrimaryCloseAngleNP`、`SecondaryOpenAngleNP`、`SecondaryCloseAngleNP` 四个属性
- 支持 INDI 面板直接修改角度
- 连接时自动同步角度到设备
- 角度值持久化到 INDI 配置

#### 🆕 自定义 ASCOM 驱动 (`ascom/DarkLightDriver/`)
- 从头编写开源 ASCOM CoverCalibrator V2 驱动（原版无源码）
- Setup 界面中直接配置角度
- 连接时自动同步到固件 EEPROM
- 完整支持 Cover / Calibrator 所有标准接口
- .NET Framework 4.8 / C# 实现

### 串口协议新增命令

| 命令 | 功能 |
|---|---|
| `UO<N>` / `UC<N>` | 设置主舵机开/关角度 |
| `VO<N>` / `VC<N>` | 设置副舵机开/关角度 |
| `uO` / `i` | 查询主舵机开/关角度 |
| `vO` / `vC` | 查询副舵机开/关角度 |

详见 [串口协议文档](protocol.md)。

## 2025-06 — Gemini FlatPanel 风格配置界面 + Jog 直驱

### 新增

#### 固件
- 新增 `J<angle>` / `j` 命令：主舵机直驱到指定角度 / 查询当前位置
- 新增 `K<angle>` / `k` 命令：副舵机直驱 / 查询当前位置
- Jog 不改变保存的开合角度，适用于实时微调

#### ASCOM 驱动
- **全新 Gemini FlatPanel 风格 Setup 界面**：
  - 双面板布局（主舵机 / 副舵机）
  - 关闭方向 / 打开方向 两组控制
  - ±1° / ±10° / ±45° 实时微调按钮
  - 「设为关闭位置」「设为打开位置」一键保存
  - 连接状态指示 + 固件版本显示
  - 重设按钮恢复默认角度
  - 深色主题 UI
- 新增 `JogPrimary()`、`JogSecondary()`、`GetPrimaryPosition()`、`GetSecondaryPosition()` 方法
- 新增 `SetCurrentAsOpen()`、`SetCurrentAsClose()` 快捷方法

### 使用方式
1. 连接设备后打开 Properties → Setup 界面
2. 点 ±1°/±10°/±45° 实时看舵机移动
3. 到位后点「设为关闭/打开位置」保存
4. Done 关闭，角度已写入 EEPROM

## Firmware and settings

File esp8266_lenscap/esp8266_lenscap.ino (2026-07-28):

/*
  Name:    ESP8266 Lens Cap Controller
  Board:   Wemos D1 Mini / NodeMCU (ESP8266)
  Author:  Generated for DLCoverCalibrator project
  Date:    2025-07-06
  Version: 1.2.2

  Description: WiFi-controlled telescope lens cap using a servo.
               - Built-in web server for phone/browser control
               - Physical button for manual toggle
               - FULL DLC serial protocol support — works with ASCOM/INDI drivers
               - EEPROM-backed angle persistence

  Hardware:
    - Wemos D1 Mini (ESP8266)
    - Servo: signal -> D2 (GPIO4), power -> external 5V
    - Button: D1 (GPIO5) -> GND (internal pullup)
    - Optional LED: D3 (GPIO0) -> GND (active LOW on some boards, check your model)

  Power: Servo MUST be powered from external 5V, NOT from 3.3V pin.
         When powered via USB, the 5V pin provides USB power (sufficient for SG90).
         For MG996R or larger servos, use a separate 5V/2A supply.

  WiFi:  Creates a unique "LensCap-<chipid>" AP and optionally joins a STA network.
         Open http://192.168.4.1 for control and /config for STA configuration.

  ASCOM/INDI Compatibility:
    This firmware implements the FULL DLC serial protocol.
    The ASCOM driver polls P (cover), L (calibrator), B (brightness),
    M (max brightness), R (heater) every cycle.
    The flat-panel output supports L/B/M/T/F commands with 0-255 PWM brightness.
    Heater and environmental sensor commands return compatible placeholder values.
    USB serial and TCP port 4030 share the same framed DLC protocol.
*/

#include <ESP8266WiFi.h>
#include <ESP8266WebServer.h>
#include <Servo.h>
#include <EEPROM.h>

// ==================== USER CONFIGURATION ====================

// --- WiFi Settings ---
// AP mode (default): ESP creates its own WiFi network
char apSSID[18] = {0};                // LensCap-<6-digit chip ID>
char deviceId[7] = {0};
const char* apPassword = "telescope";  // at least 8 chars; "" = open network

// STA mode is configured at runtime from http://192.168.4.1/config.
// The AP remains available while STA is enabled so configuration can be recovered.

// --- Servo Settings ---
const uint8_t SERVO_PIN = 4;          // D2 (GPIO4) on Wemos D1 Mini
const uint16_t SERVO_MIN_US = 500;    // min pulse width (μs) — check servo datasheet
const uint16_t SERVO_MAX_US = 2500;   // max pulse width (μs)
uint16_t openAngle = 0;               // servo angle when cap is OPEN (0-270) *adjustable via ASCOM
uint16_t closeAngle = 180;            // servo angle when cap is CLOSED (0-270) *adjustable via ASCOM
const uint16_t MOVE_TIME_MS = 10000;  // time to complete open/close movement (10s)
const uint16_t JOG_TIME_PER_270_DEG_MS = 10000;  // 10s for a full 270-degree jog
const uint16_t MIN_JOG_DURATION_MS = 750;  // keep small calibration moves visibly smooth
const uint16_t SERVO_UPDATE_INTERVAL_MS = 20;    // update pulse target at 50Hz

// --- Button Settings ---
const uint8_t BUTTON_PIN = 5;         // D1 (GPIO5), button to GND, uses internal pullup
const uint16_t DEBOUNCE_MS = 200;     // debounce time

// --- LED Settings (optional) ---
const uint8_t LED_PIN = 0;            // D3 (GPIO0), active LOW on most Wemos boards
// #define LED_ACTIVE_HIGH             // uncomment if your LED is active HIGH

// --- Flat Panel Light Settings ---
const uint8_t LIGHT_PIN = 14;        // D5 (GPIO14), PWM output for flat panel LED
const uint8_t MAX_BRIGHTNESS = 255;  // 0-255 steps
const uint32_t LIGHT_PWM_FREQ = 4000; // 4kHz PWM

// --- Serial Settings ---
const uint32_t SERIAL_BAUD = 115200;  // for USB serial control (ASCOM/INDI)
const uint16_t TCP_PORT = 4030;       // WiFi ASCOM/INDI control

// --- EEPROM ---
#define EEPROM_MAGIC 0xDA            // magic byte to check if EEPROM is initialized
#define EEPROM_ADDR_MAGIC 0
#define EEPROM_ADDR_OPEN_LOW  1
#define EEPROM_ADDR_OPEN_HIGH 2
#define EEPROM_ADDR_CLOSE_LOW 3
#define EEPROM_ADDR_CLOSE_HIGH 4
#define EEPROM_ADDR_STATE     5      // last known cover state (1=Closed, 3=Open)
#define EEPROM_SIZE           128
#define EEPROM_WIFI_MAGIC     0x57494649UL  // "WIFI"
#define EEPROM_ADDR_WIFI_MAGIC   16
#define EEPROM_ADDR_WIFI_ENABLED 20
#define EEPROM_ADDR_WIFI_SSID    21
#define EEPROM_ADDR_WIFI_PASS    54
#define WIFI_SSID_MAX_LEN        32
#define WIFI_PASS_MAX_LEN        63

// ==================== END OF USER CONFIGURATION ====================

// --- Global State ---
Servo capServo;
bool servoAttached = false;
ESP8266WebServer server(80);
WiFiServer tcpServer(TCP_PORT);
WiFiClient tcpClient;

enum CoverState {
  COVER_CLOSED = 1,
  COVER_MOVING = 2,
  COVER_OPEN   = 3,
  COVER_ERROR  = 5
};

CoverState currentState = COVER_CLOSED;
unsigned long moveStartTime = 0;
bool isMoving = false;
bool movingToOpen = false;  // track direction: true=opening, false=closing
uint16_t targetAngle = 0;
uint16_t currentServoAngle = 0;
uint16_t currentServoPulseUs = SERVO_MIN_US;
uint16_t movementStartPulseUs = SERVO_MIN_US;
unsigned long lastServoUpdateTime = 0;

// --- Jog state (smooth temporary move) ---
bool jogActive = false;
uint16_t jogStartAngle = 0;
uint16_t jogTargetAngle = 0;
uint16_t jogStartPulseUs = SERVO_MIN_US;
unsigned long jogStartTime = 0;
uint32_t jogDurationMs = 0;

// --- Flat Panel Light State ---
uint8_t lightBrightness = 0;          // current brightness (0-255)
bool lightOn = false;

// --- Button ---
unsigned long lastButtonCheck = 0;
bool lastButtonState = HIGH;

// --- Serial Command Buffer (DLC-compatible subset) ---
const uint8_t MAX_SERIAL_CHARS = 16;
char serialBuffer[MAX_SERIAL_CHARS];
uint8_t serialIndex = 0;
bool serialComplete = false;
char tcpBuffer[MAX_SERIAL_CHARS];
uint8_t tcpIndex = 0;

// --- Runtime WiFi Settings ---
bool staEnabled = false;
char staSSID[WIFI_SSID_MAX_LEN + 1] = {0};
char staPassword[WIFI_PASS_MAX_LEN + 1] = {0};
bool restartPending = false;
unsigned long restartAt = 0;

uint16_t angleToPulse(uint16_t angle);
void attachServoAtLogicalPosition();

// ==================== SETUP ====================

void setup() {
  // --- Servo pin: hold LOW IMMEDIATELY to prevent twitch during boot ---
  digitalWrite(SERVO_PIN, LOW);
  pinMode(SERVO_PIN, OUTPUT);
  digitalWrite(SERVO_PIN, LOW);

  Serial.begin(SERIAL_BAUD);
  Serial.println();
  Serial.println(F("ESP8266 Lens Cap Controller v1.2.2"));

  snprintf(deviceId, sizeof(deviceId), "%06X", ESP.getChipId());
  snprintf(apSSID, sizeof(apSSID), "LensCap-%s", deviceId);

  // --- EEPROM ---
  EEPROM.begin(EEPROM_SIZE);
  loadAnglesFromEEPROM();
  loadWiFiSettings();

  // Read saved state early (needed for initAngle) but DON'T attach servo yet.
  // GPIO4 stays OUTPUT LOW during WiFi init to prevent boot twitch.
  uint8_t savedState = EEPROM.read(EEPROM_ADDR_STATE);
  currentState = (savedState == COVER_OPEN) ? COVER_OPEN : COVER_CLOSED;
  uint16_t initAngle = (currentState == COVER_OPEN) ? openAngle : closeAngle;
  targetAngle = initAngle;  // track the known position
  currentServoAngle = initAngle;
  currentServoPulseUs = angleToPulse(initAngle);
  movementStartPulseUs = currentServoPulseUs;

  // --- Flat Panel Light ---
  pinMode(LIGHT_PIN, OUTPUT);
  analogWrite(LIGHT_PIN, 0);        // init channel
  analogWriteFreq(LIGHT_PWM_FREQ);  // 4kHz

  // --- Button ---
  pinMode(BUTTON_PIN, INPUT_PULLUP);

  // --- LED ---
  pinMode(LED_PIN, OUTPUT);
  setLED(false);

  // --- WiFi ---
  startWiFi();

  // --- Web Server ---
  setupWebServer();
  server.begin();
  Serial.println(F("Web server started."));
  tcpServer.begin();
  tcpServer.setNoDelay(true);
  Serial.print(F("DLC TCP server started on port "));
  Serial.println(TCP_PORT);

  // Keep the servo output disabled at startup. Opening a USB serial connection
  // can reset the ESP8266; attaching a servo during that reset can create an
  // immediate high-current position jump. The first movement command attaches
  // at the EEPROM-backed logical position and then uses the normal 10 s ramp.
  Serial.println(F("Ready."));
}

void startWiFi() {
  WiFi.persistent(false);
  WiFi.mode(staEnabled ? WIFI_AP_STA : WIFI_AP);
  WiFi.hostname(apSSID);
  WiFi.softAP(apSSID, apPassword);
  Serial.print(F("AP Mode: "));
  Serial.print(apSSID);
  Serial.print(F(" | IP: "));
  Serial.println(WiFi.softAPIP());

  if (!staEnabled || staSSID[0] == '\0') return;

  WiFi.begin(staSSID, staPassword);
  Serial.print(F("Connecting STA to "));
  Serial.print(staSSID);
  int attempts = 0;
  while (WiFi.status() != WL_CONNECTED && attempts < 20) {
    delay(500);
    Serial.print('.');
    attempts++;
  }

  if (WiFi.status() == WL_CONNECTED) {
    Serial.print(F("\nSTA connected | IP: "));
    Serial.println(WiFi.localIP());
  } else {
    Serial.println(F("\nSTA connection failed; AP remains available."));
  }
}

// ==================== WEB SERVER ====================

void setupWebServer() {
  server.on("/", handleRoot);
  server.on("/open", handleOpen);
  server.on("/close", handleClose);
  server.on("/status", handleStatus);
  server.on("/toggle", handleToggle);
  server.on("/light/status", HTTP_GET, handleLightStatus);
  server.on("/light/set", HTTP_POST, handleLightSet);
  server.on("/light/off", HTTP_POST, handleLightOff);
  server.on("/config", HTTP_GET, handleConfig);
  server.on("/config/save", HTTP_POST, handleSaveConfig);
  server.on("/config/angles", HTTP_POST, handleSaveAngles);
  server.on("/config/position", HTTP_GET, handleCalibrationPosition);
  server.on("/config/jog", HTTP_POST, handleCalibrationJog);
  server.on("/config/save-position", HTTP_POST, handleSaveCalibrationPosition);
  server.onNotFound(handleRoot);
}

void handleRoot() {
  String html = R"rawliteral(
<!DOCTYPE html>
<html lang="zh">
<head>
  <meta charset="UTF-8">
  <meta name="viewport" content="width=device-width, initial-scale=1.0, user-scalable=no">
  <title>Lens Cap Control</title>
  <style>
    * { box-sizing: border-box; margin: 0; padding: 0; }
    body {
      font-family: -apple-system, BlinkMacSystemFont, 'Segoe UI', Roboto, sans-serif;
      background: #1a1a2e; color: #eee; display: flex;
      justify-content: center; align-items: center; min-height: 100vh;
      padding: 20px;
    }
    .container {
      background: #16213e; border-radius: 20px; padding: 30px;
      max-width: 400px; width: 100%; text-align: center;
      box-shadow: 0 10px 40px rgba(0,0,0,0.5);
    }
    h1 { font-size: 1.6rem; margin-bottom: 8px; }
    .status {
      display: inline-block; padding: 6px 16px; border-radius: 20px;
      font-weight: bold; font-size: 0.9rem; margin: 12px 0 20px;
    }
    .status.open { background: #2ecc71; color: #fff; }
    .status.closed { background: #e74c3c; color: #fff; }
    .status.moving { background: #f39c12; color: #fff; animation: pulse 0.8s infinite; }
    @keyframes pulse { 0%,100%{opacity:1} 50%{opacity:0.5} }
    .btn {
      display: block; width: 100%; padding: 18px; margin: 12px 0;
      font-size: 1.2rem; font-weight: bold; border: none; border-radius: 12px;
      cursor: pointer; transition: transform 0.1s, opacity 0.2s;
      color: #fff;
    }
    .btn:active { transform: scale(0.96); }
    .btn:disabled { opacity: 0.4; pointer-events: none; }
    .btn-open { background: linear-gradient(135deg, #2ecc71, #27ae60); }
    .btn-close { background: linear-gradient(135deg, #e74c3c, #c0392b); }
    .btn-toggle { background: linear-gradient(135deg, #3498db, #2980b9); }
    .panel { margin-top: 22px; padding-top: 18px; border-top: 1px solid #34415f; }
    .panel h2 { font-size: 1.1rem; margin-bottom: 12px; }
    .light-row { display: flex; gap: 10px; align-items: center; }
    .light-row input[type=range] { flex: 1; }
    .light-value { width: 58px; padding: 7px; border: 1px solid #405174; border-radius: 7px; background: #101a33; color: #fff; text-align: center; }
    .light-actions { display: flex; gap: 10px; margin-top: 10px; }
    .light-actions button { flex: 1; padding: 11px; border: 0; border-radius: 9px; color: #fff; font-weight: bold; }
    .light-on { background: #9b59b6; } .light-off { background: #596275; }
    .info { font-size: 0.8rem; color: #888; margin-top: 20px; }
    .nav { display: inline-block; color: #8ab4f8; margin-top: 18px; text-decoration: none; }
  </style>
</head>
<body>
  <div class="container">
    <h1>🔭 电动镜头盖</h1>
    <div id="status" class="status closed">● 已关闭</div>
    <button class="btn btn-open" onclick="fetch('/open');updateStatus();" id="btnOpen">📂 开盖</button>
    <button class="btn btn-close" onclick="fetch('/close');updateStatus();" id="btnClose">📁 关盖</button>
    <button class="btn btn-toggle" onclick="fetch('/toggle');updateStatus();">🔄 切换</button>
    <div class="panel">
      <h2>平场灯</h2>
      <div class="light-row">
        <input id="lightSlider" type="range" min="1" max="255" value="128" oninput="syncLightValue(this.value)">
        <input id="lightValue" class="light-value" type="number" min="1" max="255" value="128" oninput="syncLightSlider(this.value)">
      </div>
      <div class="light-actions">
        <button class="light-on" onclick="turnLightOn()">开灯 / 应用亮度</button>
        <button class="light-off" onclick="turnLightOff()">关灯</button>
      </div>
      <div id="lightStatus" class="info">平场灯已关闭</div>
    </div>
    <a class="nav" href="/config">设备配置</a>
    <div class="info">设备 ID：{{DEVICE_ID}}<br>AP：{{AP_SSID}}<br>Lens Cap Controller | ESP8266</div>
  </div>
  <script>
    async function getStatus() {
      try {
        const r = await fetch('/status');
        const s = await r.text();
        const statusEl = document.getElementById('status');
        const btnOpen = document.getElementById('btnOpen');
        const btnClose = document.getElementById('btnClose');
        if (s == '3') {
          statusEl.textContent = '● 已打开'; statusEl.className = 'status open';
          btnOpen.disabled = true; btnClose.disabled = false;
        } else if (s == '1') {
          statusEl.textContent = '● 已关闭'; statusEl.className = 'status closed';
          btnOpen.disabled = false; btnClose.disabled = true;
        } else if (s == '2') {
          statusEl.textContent = '◉ 移动中...'; statusEl.className = 'status moving';
          btnOpen.disabled = true; btnClose.disabled = true;
        }
      } catch(e) {}
    }
    function updateStatus() { setTimeout(getStatus, 500); }
    function syncLightValue(v) { document.getElementById('lightValue').value = v; }
    function syncLightSlider(v) {
      v = Math.max(1, Math.min(255, Number(v) || 1));
      document.getElementById('lightSlider').value = v;
    }
    async function getLightStatus() {
      try {
        const s = await (await fetch('/light/status')).json();
        document.getElementById('lightStatus').textContent = s.on ? `平场灯已开启 · 亮度 ${s.brightness}` : '平场灯已关闭';
        if (s.brightness > 0) {
          document.getElementById('lightSlider').value = s.brightness;
          document.getElementById('lightValue').value = s.brightness;
        }
      } catch(e) {}
    }
    async function turnLightOn() {
      const value = Math.max(1, Math.min(255, Number(document.getElementById('lightValue').value) || 1));
      await fetch(`/light/set?brightness=${value}`, {method:'POST'}); getLightStatus();
    }
    async function turnLightOff() { await fetch('/light/off', {method:'POST'}); getLightStatus(); }
    setInterval(getStatus, 3000);
    setInterval(getLightStatus, 3000);
    getStatus();
    getLightStatus();
  </script>
</body>
</html>
)rawliteral";
  html.replace("{{DEVICE_ID}}", deviceId);
  html.replace("{{AP_SSID}}", apSSID);
  server.send(200, "text/html; charset=utf-8", html);
}

String htmlEscape(const char* value) {
  String escaped;
  escaped.reserve(strlen(value) + 8);
  for (const char* p = value; *p; ++p) {
    switch (*p) {
      case '&': escaped += F("&amp;"); break;
      case '<': escaped += F("&lt;"); break;
      case '>': escaped += F("&gt;"); break;
      case '"': escaped += F("&quot;"); break;
      case '\'': escaped += F("&#39;"); break;
      default: escaped += *p; break;
    }
  }
  return escaped;
}
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
void loop() {
  server.handleClient();
  unsigned long now = millis();

  if (restartPending && (long)(millis() - restartAt) >= 0) {
    ESP.restart();
  }

  checkButton();
  checkSerial();
  checkTcp();
  
  // --- Handle open/close movement ---
  if (isMoving) {
    unsigned long elapsed = now - moveStartTime;
    
    if (elapsed >= MOVE_TIME_MS) {
      // Movement complete
      moveToAngle(targetAngle);
      isMoving = false;
      currentState = movingToOpen ? COVER_OPEN : COVER_CLOSED;
      // Save state to EEPROM so we restore correct position after power loss
      EEPROM.write(EEPROM_ADDR_STATE, (uint8_t)currentState);
      EEPROM.commit();
    } else if (now - lastServoUpdateTime >= SERVO_UPDATE_INTERVAL_MS) {
      // Interpolate pulse width directly for smooth fixed-rate motion.
      int32_t pulseDelta = (int32_t)angleToPulse(targetAngle) - movementStartPulseUs;
      uint16_t currentPulseUs = movementStartPulseUs +
                                ((int64_t)pulseDelta * elapsed) / MOVE_TIME_MS;
      moveToPulse(currentPulseUs);
      lastServoUpdateTime = now;
    }
  }

  // --- Handle jog movement (smooth, no state change) ---
  if (jogActive) {
    unsigned long elapsed = now - jogStartTime;
    if (elapsed >= jogDurationMs) {
      moveToAngle(jogTargetAngle);
      targetAngle = jogTargetAngle;
      jogActive = false;
    } else if (now - lastServoUpdateTime >= SERVO_UPDATE_INTERVAL_MS) {
      int32_t pulseDelta = (int32_t)angleToPulse(jogTargetAngle) - jogStartPulseUs;
      uint16_t currentPulseUs = jogStartPulseUs +
                                ((int64_t)pulseDelta * elapsed) / jogDurationMs;
      moveToPulse(currentPulseUs);
      lastServoUpdateTime = now;
    }
  }
  
  // --- LED heartbeat (on when moving) ---
  if (isMoving) {
    static unsigned long lastLEDToggle = 0;
    if (millis() - lastLEDToggle > 250) {
      static bool ledState = false;
      ledState = !ledState;
      setLED(ledState);
      lastLEDToggle = millis();
    }
  } else {
    setLED(currentState == COVER_OPEN);
  }
  
  yield();   // feed ESP8266 watchdog + WiFi stack
  delay(10); // yield to WiFi stack
}

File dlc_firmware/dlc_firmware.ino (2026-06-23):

/*
  Name:         DarkLight Cover Calibrator (DLC)
  Author:       Nathan Woelfle
  Contributors: Taylor J (Initial Dew Heater Integration)
  Date:         6/27/25

  Version: 1.2.0
  *View GitHub Wiki for version change details
  https://github.com/10thTeeAstronomy/DarkLight_CoverCalibrator/wiki/Firmware-Version-History
  
  Description: The DarkLight Cover Calibrator is a DIY project to build a 
                motorized telescope cover, flat panel, or a combined flip-flat system.
                It is full supported and compliant device on the INDI platform or
                with ASCOM 6.5+ or newer using the ICoverCalibrator driver.

              https://github.com/10thTeeAstronomy/DarkLight_CoverCalibrator

  (c) Copyright Nathan Woelfle 2020-present day. All Rights Reserved.

  This project is protected by International Copyright Law.
  Permission is granted for personal and Academic/Educational use only.
  Software and hardware distributed under Creative Commons Attribution-NonCommercial License

  For more information, please refer to the full terms of the Creative Commons Attribution-NonCommercial 4.0 International License:
  https://creativecommons.org/licenses/by-nc/4.0/
*/

//-----------------------------------------------------------
//----- IF UNSURE HOW TO SETUP, SEE MANUAL FOR DETAILS  -----
//-----------------------------------------------------------

//----- (UA) USER-ADJUSTABLE OPTIONS ------
#define COVER_INSTALLED //comment out if not utilized
#define LIGHT_INSTALLED //comment out if not utilized
#define HEATER_INSTALLED //comment out if not utilized
#define ENABLE_SERIAL_CONTROL //comment out if not utilized
#define ENABLE_MANUAL_CONTROL //comment out if not utilized
#define ENABLE_SAVING_TO_MEMORY //comment out if not utilized
//#define SHOW_HEARTBEAT //for debugging purposes only. shows loop is active, uncomment to flash builtin led
const uint32_t serialSpeed = 115200; //values are: (9600, 19200, 38400, 57600, (default 115200), 230400)

//----- (UA) (COVER) -----
const uint32_t timeToMoveCover = 5000;  //(ms) time it takes to move between open/close positions (set between 1000(fast)-10000(slow) ms, recommend (5000 ms))

//----- (UA) (COVER) PRIMARY SERVO PARAMETERS -----
const uint16_t primaryServoMinPulseWidth = 500; //refer to servo manufacture for usec pulses and set accordingly
const uint16_t primaryServoMaxPulseWidth = 2500; //refer to servo manufacture for usec pulses and set accordingly
uint16_t primaryServoOpenCoverAngle = 0; //position angle servo opens to, value between (0-270), *now adjustable via serial/ASCOM/INDI
uint16_t primaryServoCloseCoverAngle = 180; //position angle servo closes to, value between (0-270), *now adjustable via serial/ASCOM/INDI

//----- (UA) (COVER) SECONDARY SERVO PARAMETERS -----
//#define SECONDARY_SERVO_INSTALLED //uncomment if using additional servo
const uint16_t secondaryServoMinPulseWidth = 500; //refer to servo manufacture for usec pulses and set accordingly
const uint16_t secondaryServoMaxPulseWidth = 2500; //refer to servo manufacture for usec pulses and set accordingly
uint16_t secondaryServoOpenCoverAngle = 0; //position angle servo opens to, value between (0-270), *now adjustable via serial/ASCOM/INDI
uint16_t secondaryServoCloseCoverAngle = 180; //position angle servo closes to, value between (0-270), *now adjustable via serial/ASCOM/INDI

//----- (UA) (COVER) SELECT A MOVEMENT -----
//----- UNCOMMENT ONLY ONE OPTION, SEE MANUAL FOR DETAILS -----
#define USE_LINEAR
//#define USE_CIRCULAR
//#define USE_CUBIC
//#define USE_EXPO
//#define USE_QUAD
//#define USE_QUART
//#define USE_QUINT
//#define USE_SINE

//----- (UA) (LIGHT) -----
uint8_t maxBrightness = 255; //choose one of the following max number of steps: (max # of levels:steps between each value) -> ((light will be on or off 1:255), default 5:51, 17:15, 51:5, 85:3, (default 255:1))
bool autoON = false; //adjust only if using manual-only mode, see manual for details 

//----- (UA) (HEATER) -----
const uint32_t heaterShutoff = 3600000; //(ms) max time for manual heating (3600000 = one hour)
const float deltaPoint = 5.0;  //(degrees) target temperature difference above ambient temp for dew control

//----- (UA) (HEATER) NUMBER OF HEATING MODULES -----
//----- UNCOMMENT UP TO TWO (2) HEATERS, SEE MANUAL FOR DETAILS -----
#define HEATER_ONE_INSTALLED
#define HEATER_TWO_INSTALLED

//----- (UA) (HEATER) TEMPERATURE & HUMIDTY SENSOR -----
//----- UNCOMMENT ONLY ONE OPTION, SEE MANUAL FOR DETAILS -----
#define ENABLE_BME280
//#define ENABLE_DHT22

//----- (UA) (BUTTONS) -----
const uint32_t debounceDelay = 150; //(ms) debounce time for the buttons *may need adjusting, see manual for details

//----- END OF (UA) USER-ADJUSTABLE OPTIONS -----
//-----------------------------------------------
//-------------- DO NOT EDIT BELOW --------------
//-----------------------------------------------
//------------ VARIABLE DECLARATION -------------

// Map 0-270° to us pulse width (Arduino Servo.write() caps at 180°, use writeMicroseconds)
#define SERVO_US(angle, minPw, maxPw) map(constrain(angle, 0, 270), 0, 270, minPw, maxPw)

//----- VERSIONING CONTROL -----
const char* dlcVersion = "v1.2.0";

//----- MEMORY -----
#ifdef ENABLE_SAVING_TO_MEMORY
  #include <EEPROMWearLevel.h>
  #define EEPROM_LAYOUT_VERSION 1
  #define AMOUNT_OF_INDEXES 8
  #define EEPROM_LENGTH_TOUSE 1023
  #define SAVED_COVER_STATE 0
  #define SAVED_PANEL_VALUE 1
  #define SAVED_BROADBAND_VALUE 2
  #define SAVED_NARROWBAND_VALUE 3
  #define SAVED_PRIMARY_OPEN_ANGLE 4
  #define SAVED_PRIMARY_CLOSE_ANGLE 5
  #define SAVED_SECONDARY_OPEN_ANGLE 6
  #define SAVED_SECONDARY_CLOSE_ANGLE 7
#endif

//----- PIN ASSIGNMENT -----
const uint8_t lightPanel = 3;
const uint8_t chOneHeatTempSensor = 4;
const uint8_t chOneHeater = 5;
const uint8_t chTwoHeater = 6;
const uint8_t chTwoHeatTempSensor = 7;
const uint8_t dhtSensor = 8;
const uint8_t primeServo = 9;
const uint8_t secondServo = 10;
//PIN 13 RESERVED for LED_BUILTIN
const uint8_t servoButton = A1;
const uint8_t lightButton = A2;
//PIN A4 RESERVED for BME280 I2C -> SDA
//PIN A5 RESERVED for BME280 I2C -> SCL

//----- COMM FOR ASCOM / INDI -----
uint8_t currentCoverState; //reports # 0:NotPresent, 1:Closed, 2:Moving, 3:Open, 4:Unknown, 5:Error
uint8_t calibratorState = 1; //reports # 0:NotPresent, 1:Off, 2:NotReady, 3:Ready, 4:Unknown, 5:Error
uint8_t heaterState; //reports # 0:NotPresent, 1:Off, 3:On, 4:Unknown, 5:Error, 6:Set (HeatOnClose)
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

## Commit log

2025-06-07 add schematics
2025-06-12 - update to servo(s)
2025-06-27 New files (#4)
    * Added CODEOWNERS.md
    * Added SECURITY.md
    * Add README.md to support firmware installation
    * correct file naming
    * replace with correct naming
    * add action to compile and verify dlc_firmware
    * Move wording
    * update comments to verify actions work
    [dlc_firmware.ino]
2025-06-27 New files (#5)
    * update to test workflow
    * checking workflow
    * update workflow naming
    ---------
    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
    [dlc_firmware.ino]
2025-06-27 Fix folders and update action (#10)
    * incorrect structure
    * update arduino workflow
2025-07-10 replace schematics (#13)
    update polarized capacitors
2026-06-20 feat: servo angle runtime config + open-source ASCOM driver + docs
    - Firmware: servo angles now runtime-configurable via serial (UO/UC/VO/VC)
    - Firmware: angle settings persist to EEPROM
    - INDI driver: add angle properties in Options panel
    - ASCOM: new open-source driver (C#/.NET) with setup dialog for angles
    - Docs: comprehensive documentation in docs/ directory
    - Serial protocol: 8 new commands for angle get/set
2026-06-20 feat: Gemini-style setup UI with live jog (\u00b11\u00b0/\u00b110\u00b0/\u00b145\u00b0) and one-click angle save
    Firmware:
    - Add J<angle>/j commands for primary servo jog & position query
    - Add K<angle>/k commands for secondary servo jog & position query
    - Jog writes servo directly without changing saved open/close angles
    ASCOM Driver:
    - Redesigned SetupDialogForm with Gemini FlatPanel-style dark UI
    - Dual panel layout (servo 1 / servo 2) with Close/Open sections
    - \u00b11\u00b0/\u00b110\u00b0/\u00b145\u00b0 live jog buttons with gear icons
    - 'Set as Close'/'Set as Open' one-click position capture
    - Connection status indicator + firmware version display
    - Reset button for default angles (0\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
    [dlc_firmware.ino]
2026-06-23 feat: 270° servo support + INDI jog buttons + ASCOM-style angle controls
    - Change angle vars uint8_t→uint16_t, constrain 0→270
    - Replace Servo.write() with writeMicroseconds() for true 0-270°
    - Remove Servo.read() (broken with writeMicroseconds)
    - Add J{angle} and j position query commands
    INDI driver:
    - Add step-select radio + Jog Open/Close push buttons
    - Add Set as Open/Close Pos save buttons
    - Use J command for physical servo jogging (real movement)
    - Support 0-270° range in all angle controls
    - Fix FindINDI.cmake version regex for INDI 2.2.x
    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
    [darklight_covercalibrator.cpp, dlc_firmware.ino]
2026-07-09 feat: add ESP8266 lens cap controller firmware
    - WiFi web control + DLC serial protocol (full ASCOM/INDI compatible)
    - EEPROM-backed angle persistence
    - Direction-aware state tracking (fixes openAngle==closeAngle bug)
    - Safe angle defaults with auto-correction on boot
    - Supports 0-270 degree servos
    [esp8266_lenscap.ino]
2026-07-09 fix: ESP8266 crash on connect, auto-close on boot, and UI improvements
    ESP8266 Firmware (esp8266_lenscap.ino):
    - Fix atoi param parsing bug for UO<N>/UC<N>/VO<N>/VC<N> commands
    (atoi("C180") returned 0 instead of 180, causing wrong angle saves)
    - Remove Serial.print debug output from EEPROM save/load functions
    (was polluting DLC protocol responses, causing INDI buffer overflow)
    - Save/restore cover state on boot instead of always closing
    (prevents dangerous auto-close after power loss during observation)
    - Add yield() in main loop to prevent ESP8266 WDT resets
    - Fix vO/vC/K/k commands to return ? for uninstalled secondary servo
    - Remove unsolicited Serial output from openCover/closeCov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
    [darklight_covercalibrator.cpp, esp8266_lenscap.ino]
2026-07-10 fix: stabilize cover calibration workflow
    Refresh ASCOM angles from firmware, jog relative to the current servo position, and clean stale driver registrations during install.
    Track ESP8266 servo position and move with 5s/270deg eased motion.
    [esp8266_lenscap.ino]
2026-07-13 feat(firmware): add flat panel PWM control
2026-07-13 feat: flat panel light control, servo fixes, INDI brightness overhaul
    ESP8266 Firmware:
    - Add flat panel PWM control on GPIO14 (D5): T<N>/F/B/M/L commands
    - Brightness 0-255 linear mapping via analogWrite
    - Move servo attach to first line of setup() to minimize boot twitch
    - Attach servo before WiFi init so it holds position during boot
    - Save/restore cover state on EEPROM to survive power loss
    Known issue: PWM flicker
    - Default ~1kHz PWM is flicker-free to eyes but visible on phone cameras
    - analogWriteFreq(20000) + analogWriteRange(255) don't work reliably
    on GPIO14 with ESP8266 Arduino core — freq setting is silently ignored,
    causing visible flicker at low brightness
    - Moving freq/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
    [darklight_covercalibrator.cpp, esp8266_lenscap.ino]
2026-07-14 fix(firmware): switch to 4kHz PWM for flat panel
    Use 4kHz PWM via analogWriteFreq(4000) after channel init.
    Default ~1kHz is flicker-free to eyes but 4kHz reduces camera banding.
    Known issues (PC817 optocoupler limitation):
    - T5 and below: not lit (pulse too narrow for ~18us turn-on time)
    - T6: significantly brighter than T5 (non-linear conduction knee)
    - Low brightness has non-linear response due to optocoupler threshold
    - Phone cameras may still see some banding at 4kHz
    Root cause: PC817 optocoupler on the LED driver module cannot
    switch at high frequency with narrow pulses. For full 0-255
    linear range at 20kHz, replace with logic-level MOSFET driver
    (AO3400A) or similar direct-drive mod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
    [esp8266_lenscap.ino]
2026-07-15 fix(esp8266_lenscap): smooth jog, delayed servo attach, 10s move time
    - Jog command now uses smooth interpolation (JOG_TIME_MS) instead of instant move
    - Servo attach delayed until after WiFi init to prevent boot twitch
    - targetAngle properly synced with initAngle on boot (fixes 'j' query returning 0)
    - 'j' command returns interpolated position during active jog
    - Move time increased to 10s for USB power stability
    [esp8266_lenscap.ino]
2026-07-16 feat(lenscap): add network control and calibration
2026-07-28 fix: improve ESP8266 lens cap motion control
    [esp8266_lenscap.ino]
2026-07-30 fix(indi): parse current INDI version headers
2026-07-30 Add electric flat-field panel CAD models
    [主动-反.STEP, 主动臂-反向.SLDPRT, 主动臂-反向.STEP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]
2026-08-09 fix(ascom): recover CH340 disconnects
    Prevent overlapping polling callbacks from retaining stale serial handles. Rebuild the port with a DTR reset after bounded failures and remove unsupported secondary-servo controls.
